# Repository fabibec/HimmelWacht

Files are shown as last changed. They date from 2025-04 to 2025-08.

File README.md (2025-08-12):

# HimmelWacht

This repository contains all the files, documentation, and source code for the HimmelWacht project. The project integrates a Raspberry Pi for high-level processing, an ESP32 for real-time hardware control, and a laboratory computer for AI model inference.

## Project Description

This project develops a Bluetooth-controller-operated vehicle equipped with a manual and semi-automatic Nerf dart launcher. The launcher fires at a wooden glider attached to a stick and moved by a person. In manual mode, the vehicle, turret platform, and launcher are controlled via the Bluetooth controller. The semi-automatic mode uses artificial intelligence and computer vision to detect the wooden glider and automatically aim the launcher, ignoring other objects. Movement is possible along both X and Y axes, with vertical motion limited to maintain the camera’s field of view. The system assumes optimal indoor conditions for target detection and tracking.

For more details refer to the [final presentation](documents/praesi/gruppe_1_himmelwacht_praesentation.pdf)

## Repository Structure

This repository is organized into the following directories:

```
.
├── cad/                 # CAD files (FreeCAD, STL) for 3D-printed components.
├── documents/           # Project documentation, datasheets, and diagrams.
├── esp/                 # ESP32 firmware and related tools.
├── laboratory_computer/ # AI models, training scripts, and inference code.
├── raspberry/           # Software for the Raspberry Pi.
└── util/                # Miscellaneous utilities, screenshots, and test files.
```

Each directory contains a `README.md` file with more detailed information about its contents and setup instructions.

## Getting Started

To get started with a specific part of the project, please refer to the `README.md` file within the corresponding directory:

- **For the ESP32 firmware**: See `esp/HimmelWachtEsp32/README.md`
- **For the Raspberry Pi code**: See `raspberry/README.md`

General project documentation can be found in the `documents/` directory.

## Authors

- Fabian Becker
- Jendrik Jürgens
- Nicolas Koch
- Michael Specht
- Jonathan Wohlrab

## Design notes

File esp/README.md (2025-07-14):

# ESP32 Code

This directory contains all code and tools related to the ESP32 microcontroller.

## Directory Structure

```
.
├── bluepad32-v4.2.0/      # Bluepad32 library for gamepad support.
├── ds4-mac-change/        # Utility to set the MAC-address of the controller.
├── esp-idf-v5.4.1/        # ESP-IDF framework.
└── HimmelWachtEsp32/      # Main ESP32 project code.
```

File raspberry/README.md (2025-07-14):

# Raspberry Pi Code

his directory contains all code that needs to be executed on the Raspberry Pi.

## Directory Structure

```
.
├── html_server/         # Python-based web server
├── mediamtx/            # Configuration for the MediaMTX media server.
├── sensors/             # Source code for the Gyroscope and Ultrasonic sensors.
├── systemd_services/    # systemd service files.
└── webRTC_sender/       # Deprecated peer-to-peer WebRTC sender script.
```

## System Setup and Configuration

### 1. Raspberry Pi Credentials

- **Username**: `hw`
- **Password**: `dt`

Access the Raspberry Pi via SSH:
```bash
ssh hw@<IP_ADDRESS>
```

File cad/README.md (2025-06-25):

# CAD-Files

This folder contains all of our CAD Files, both the ones we designed ourself and the imported ones.

## Used models
These are the models we used and adapted for our purpose

- [Turret](https://www.thingiverse.com/thing:4870102/files)
- [Raspberry PI Case](https://www.printables.com/model/705427-retro-raspberry-pi-5-case-snap-fit)
- [Flywheel Driver Holder](https://www.printables.com/model/355368-holder-for-xy-mos-d4184-power-mosfet-breakout-modu)
- [PS4 Controller Phone Holder](https://www.printables.com/model/813863-smartphone-mount-for-ps4-controller-dualshock-4/files)

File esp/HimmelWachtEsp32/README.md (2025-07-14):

# HimmelWacht ESP32 Software

This repository contains the firmware for the ESP32 microcontroller used in the HimmelWacht project. It handles low-level hardware control, including motor operation and gamepad connectivity. The project is preconfigured for use with Visual Studio Code and the C/C++ extension.

## Getting Started

Follow these steps to set up the project, build the firmware, and flash it to the ESP32.

### Prerequisites

- **ESP-IDF v5.4.1**: This project depends on a specific version of the ESP-IDF, which is included as a Git submodule in the `esp/esp-idf-v5.4.1` directory.
- **Bluepad32 v4.2.0**: The Bluepad32 library is also included as a submodule in the `esp/bluepad32-v4.2.0` directory.

### Installation and Setup

1.  **Initialize Submodules**: If you have cloned the repository without the submodules, initialize them first:
    ```shell
    git submodule update --init --recursive
    ```

2.  **Set up ESP-IDF**: Configure the build environment by running the install and export scripts.
    ```shell
    # From the project root directory
    cd esp/esp-idf-v5.4.1
    ./install.sh
    . ./export.sh
    ```
    *Note: You may need to run the `export.sh` script in every new terminal session.*

3.  **Patch Bluepad32 and BTstack**: Apply the necessary patches to the BTstack library within Bluepad32.
    ```shell
    # From the project root directory
    cd esp/bluepad32-v4.2.0/external/btstack
    git apply ../patches/*.patch
    ```

4.  **Integrate BTstack**: Run the integration script to make the patched BTstack component available to the ESP-IDF.
    ```shell
    # From the project root directory
    cd esp/bluepad32-v4.2.0/external/btstack/port/esp32
    ./integrate_btstack.py
    ```

### Building and Flashing

After completing the setup, return to the main project directory and use the `idf.py` tool to build and flash the firmware.

1.  **Navigate to the project directory**:
    ```shell
    # From the project root directory
    cd esp/HimmelWachtEsp32
    ```

2.  **Build the project**:
    ```shell
    idf.py build
    ```

3.  **Flash the firmware**: Connect the ESP32 to your computer and flash the built firmware.
    ```shell
    idf.py flash
    ```

## Technical Details

### Motor Driver

The Pololu G2 High-Power Motor Driver 24v13 board is used to control the motors. It supports two primary control modes. The current implementation uses Sign-Magnitude mode.

#### Control Modes

1.  **Sign-Magnitude (S-M)**: The PWM duty cycle controls motor speed, and a separate digital pin (`DIR`) controls the direction.
2.  **Locked-Antiphase (L-A)**: The `PWM` pin is held high, and the PWM signal is sent to the `DIR` pin to control both speed and direction.

#### Locked-Antiphase Operation

| Duty Cycle (%) | Locked-Antiphase |
| :--- | :--- |
| 0 | Full speed reverse |
| 25 | Medium speed reverse |
| 50 | Coast (motor off) |
| 75 | Medium speed forward |
| 100 | Full speed forward |

| PWM | DIR | OUTA | OUTB | Operation |
| :-- | :-- | :--- | :--- | :--- |
| H | H | H | L | Forward |
| H | L | L | H | Reverse |
| L | X | L | L | Brake |

#### Mode Comparison

| Feature | Sign-Magnitude | Locked-Antiphase |
| :--- | :--- | :--- |
| **Ease of implementation** | ✅ Very easy | ❗ A bit more complex |
| **PWM Pin Use** | PWM → speed, DIR → direction | DIR → PWM waveform, PWM = always HIGH |
| **Idle behavior (0% duty)** | Outputs both LOW = brake | DIR at 50% duty = coast |
| **PWM frequency required** | Lower okay (~20 kHz) | ⚠️ Needs higher freq (~50–100+ kHz) |
| **EMI (Electromagnetic Interference)** | Lower | Can be noisier due to polarity switching |
| **Smoothness at low speeds** | Good | ✅ Often smoother, more linear torque |
| **Power efficiency** | Slightly better | Can generate more switching losses |
| **Torque ripple** | Can be higher | ✅ Lower, smoother torque transitions |

## Dependencies

- C11
- ESP-IDF v5.4.1
- Bluepad32 v4.2.0

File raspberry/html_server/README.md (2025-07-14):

# HTML Server

This Python script starts an HTTP server that:

- Serves a static webpage which pulls a **WebRTC stream** from a MediaMTX server running on a Raspberry Pi.
- Connects to a **WebSocket** to receive bounding-box coordinates sent from the inference script running on the laboratory PC.
- Supports **real-time video annotation** in the browser using the received data.

The script creates an additional **WebSocket** which streams the real-time date of the Gyroscope and Ultrasonic sensor.

## Configuration

All network parameters (e.g., IP address of the Lab PC, port numbers) can be configured via a `.env` file.

Example `.env`:

```env
LAB_PC_IP=172.16.3.105
HTTP_PORT=8000
WEBSOCKET_PORT=8765
```

## Usage

The server is started automatically by a `systemd` service.

To apply changes (e.g., updated source code or `.env` configuration), restart the service:

```bash
sudo systemctl restart webserver.service
```

Once running, you can access the web interface at:

```
http://<your-system-ip>:<HTTP_PORT>
```

The server will log its current IP address on startup.

## Credits

The favicon used is free to use.
Source: [Missiles icon by Freepik - Flaticon](https://www.flaticon.com/free-icon/missiles_3857446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)

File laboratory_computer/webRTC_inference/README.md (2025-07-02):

# webRTC Inference

Contains the used scripts for webrtc stream, Ai inference and combines it with MQTT, Websockets and the possiblity to track objects detected with the AI.
DEPRECATED => Was used over the course of the project but has been dropped due to requirements

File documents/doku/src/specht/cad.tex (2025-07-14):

\chapter{CAD-Konstruktion}

\section{Setup und Einarbeitung (Becker, Specht)}

Zu Beginn des Projekts wurde in Abstimmung mit Fabian Becker sowie im Austausch mit Andreas Wittmann (Studienkollege) entschieden, FreeCAD als CAD-Software zu verwenden. Der Grund hierfür war die einfache Kollaboration innerhalb der Projektgruppe sowie der unkomplizierte Erfahrungsaustausch mit der Arbeitsgruppe um A. Wittmann. Andere Softwarelösungen wie OnShape wurden diskutiert, aufgrund der Komplexität und der damit verbundenen Einarbeitungszeit im Hinblick auf die Projektlaufzeit jedoch verworfen. FreeCAD ist zudem eine Open-Source-Software, die neben Fedora- auch auf Debian-Systemen lauffähig ist. So konnte die Software problemlos auf den Arbeitsrechnern der Teammitglieder installiert werden.

Grundsätzlich stützt sich die Konstruktion auf vorhandene STL-Vorlagen. Mehrere Beispielprojekte aus dem Internet dienten als Grundlage für die Arbeit \cite{cad_turret_blueprint,cad_flywheel_blueprint,cad_esp_case_blueprint, cad_gyro_blueprint, cad_servo_v1_blueprint, cad_geometry_srf02}.

\section{Geschützarm Version 1 (Specht) \label{sec:cad_gunarm_v1}}

Bevor mit der Konstruktion begonne wurde, wurde im Team besprochen, welche Komponenten nötig sind, um die Position des Flugobjekts eindeutig zu bestimmen. Die Wahl fiel auf folgende Komponenten, die aus vorherigen Studienprojekten übernommen werden konnten:

\begin{itemize}
    \item GY-521 MPU-6050 3-Achsen-Gyroskop und Beschleunigungssensor
    \item SRF02 Ultraschall Entfernungssensor
    \item Raspberry Pi 5 Kamera Modul
    \item 2x 28BYJ-48 Schrittmotor
\end{itemize}

Ziel des ersten Entwurfs war es, diese kompakt auf dem Arm zu integrieren. Die angedachten Schrittmotoren wichen jedoch von der Vorlage aus dem Beispielprojekt \cite{cad_turret_blueprint} ab, weshalb der Geschützarm von Grund auf neu konstruiert werden musste.

Alle Module sollten zentral über der Abschusseinrichtung platziert werden, um eine korrekte Berechnung der Flugbahn zu ermöglichen. Der Ultraschall-Sensor sollte dabei hochkant nach vorne gerichtet sein, um die Entfernung zum Ziel zu messen. Die Kamera sollte schräg nach oben gerichtet sein, um den Himmel zu überwachen. Der Beschleunigungssensor sollte liegend auf dem Arm montiert werden, um die Beschleunigung des Arms zu messen. Die Schrittmotoren mussten in einem geeigneten Abstand zueinander montiert werden, sodass die Flywheel-Konstruktion des Arms funktioniert. Letzteres konnte durch das Vermessen der Vorlage aus dem Beispielprojekt \cite{cad_turret_blueprint} realisiert werden. Für die restlichen Anforderungen waren die korrekten Maße nötig. Für die Montage der Kamera konnte eine bereits 3D-gedruckte Halterung aus einer anderen Gruppe benutzt werden. Die Haltevorrichtung für den Beschleunigungssensor wurde aus einer STL-Vorlage \cite{cad_gyro_blueprint} übernommen und angepasst. Auch für die Schrittmotoren konnte auf ein Modell aus dem Internet \cite{cad_servo_v1_blueprint} zurückgegriffen werden, weshalb es nicht nötig war, die komplexe Geometrie eigenständig zu vermessen. Einzig die Maße für den Ultraschall-Sensor wurden recherchiert \cite{cad_geometry_srf02} und durch Nachmessen validiert.

\begin{figure}[h]
    \centering

    \begin{subfigure}[b]{0.45\textwidth}
        \centering
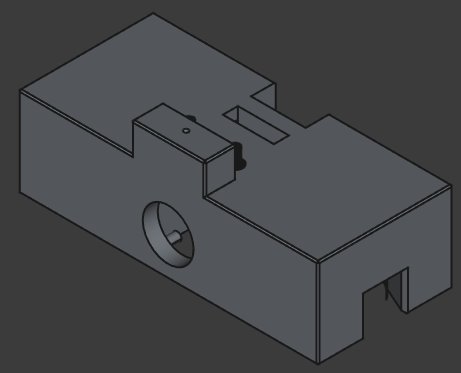
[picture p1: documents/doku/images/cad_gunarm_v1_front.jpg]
        
        \caption{Geschützarm Version 1 - Frontansicht}
    \end{subfigure}
    \hfill
    \begin{subfigure}[b]{0.45\textwidth}
        \centering
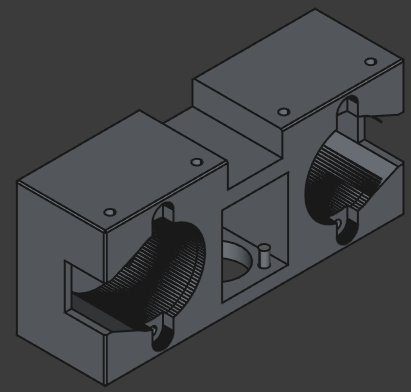
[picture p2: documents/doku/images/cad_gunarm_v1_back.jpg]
        
        \caption{Geschützarm Version 1 - Rückansicht}
    \end{subfigure}

    \caption{Geschützarm Version 1}
    \label{fig:gunarm_v1}
\end{figure}

Neben den eigentlichen Maßen der Komponenten war das Kabelmanagement ein wichtiges Thema. Alle Kabel sollten nach hinten am Magazin entlang geführt werden, um eine saubere Optik zu gewährleisten. Für Beschleunigungssensor und Kamera stellte dies kein Problem dar, da diese ganz oben angebracht sein sollten. Der Ultraschall-Sensor und die Schrittmotoren hingegen waren in das neukonstruierte Gehäuse integriert, sodass Aussparungen, wie in Abbildung~\ref{fig:gunarm_v1} zu sehen, angebracht werden mussten, um die Kabel aus dem Gehäuse herauszuführen.

Außerdem musste sichergestellt werden, dass der Geschützarm an das Magazin montiert werden kann. Hierzu wurden vom Kollegen Fabian Becker Montagepunkte am Magazin konstruiert, die mit dem Geschützarm verschraubt werden können.

\section{Geschützarm Version 2 (Specht)}

Im Laufe des Projektes wurde in Abstimmung mit Fabian Becker klar, dass die initial angedachten Schrittmotoren aufgrund zu geringer Leistung nicht für die Flywheel-Konstruktion geeignet sind. Daraufhin wurde sich für die originalen Motoren aus dem Beispielprojekt \cite{cad_turret_blueprint} entschieden. Das hatte zur Folge, dass der Geschützarm neu konstruiert werden musste, da die Maße der neuen Motoren von den Alten abwichen. Aus diesem Grund wurde der Geschützarm der Vorlage \cite{cad_turret_blueprint} als Basis genommen und die Grundidee der Version 1 beibehalten.

\begin{figure}[h]
    \centering

    \begin{subfigure}[b]{0.45\textwidth}
        \centering
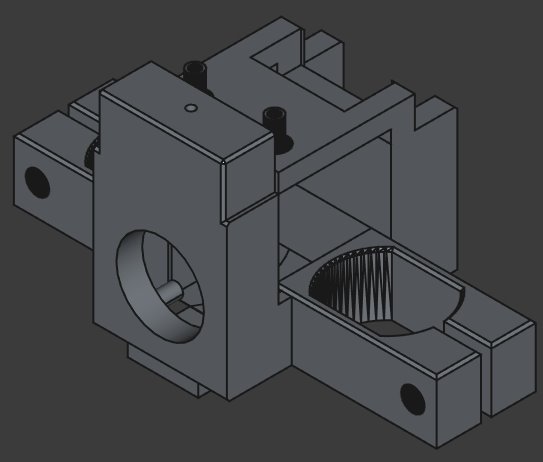
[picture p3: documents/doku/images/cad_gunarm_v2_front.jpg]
        
        \caption{Geschützarm Version 2 - Frontansicht}
    \end{subfigure}
    \hfill
    \begin{subfigure}[b]{0.45\textwidth}
        \centering
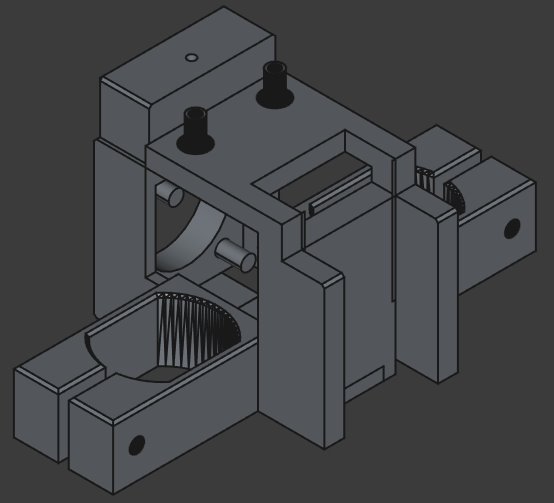
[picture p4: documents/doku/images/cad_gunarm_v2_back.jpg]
        
        \caption{Geschützarm Version 2 - Rückansicht}
    \end{subfigure}

    \caption{Geschützarm Version 2}
    \label{fig:gunarm_v2}
\end{figure}

Im Gegensatz zur Version 1 wird der Ultraschallsensor nun seitlich eingeführt anstatt von unten, siehe~\ref{fig:gunarm_v2}. Problematisch waren dabei die beschränkten Platzverhältnisse, da die Schrittmotoren näher am Kanonenrohr angebracht wurden als im vorherigen Entwurf. Außerdem wurden die zuvor angedachten Montagepunkte am Magazin wieder entfernt. Die Zusammenführung des Geschützarms mit dem Magazin erfolgte deshalb mittels Modellbaukleber.

\section{Montagehalterung Motortreiber (Specht)}

Für die ersten Funktionstests wurden die Pololu-Motoren provisorisch auf Kork-Schnipseln montiert. Dieses Vorgehen ermöglichte eine zügige Inbetriebnahme, jedoch erwies es sich hinsichtlich Stabilität und Sicherheit als unzureichend. Im Rahmen der Tests kam es zum Abrutschen eines Motors von der Korkunterlage, was zu einer kurzfristigen Wärmeentwicklung und Geruchsbildung führte. Glücklicherweise wurde eine Beschädigung der Hardware vermieden.

\begin{figure}[h]
    \centering

    \begin{subfigure}[b]{0.25\textwidth}
        \centering
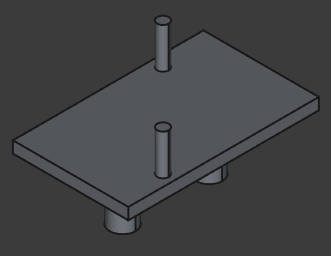
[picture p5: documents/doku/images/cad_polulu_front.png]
        
        \caption{Polulu - Draufsicht}
    \end{subfigure}
    \hspace{0.05\textwidth}
    \begin{subfigure}[b]{0.25\textwidth}
        \centering
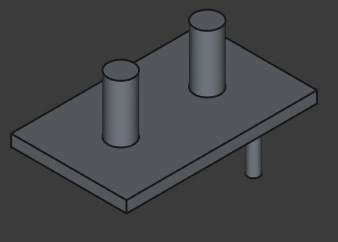
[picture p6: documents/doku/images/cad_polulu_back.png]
        
        \caption{Polulu - Bodensicht}
    \end{subfigure}

    \caption{Montagehalterung für Pololu-Motortreiber}
    \label{fig:pololu_mounting}
\end{figure}

Für die finale Abnahme wurde daher ein dauerhaftes und sicheres Montagesystem umgesetzt, das ein sauberes und zuverlässiges Setup gewährleistet. Die Maße bzw. Position der Löcher wurden dabei manuell mit Geodreieck vermessen. Wie in Abbildung~\ref{fig:pololu_mounting} zu sehen, kann die Halterung direkt auf der Montageplatte des Fahrzeugs geklippt werden.

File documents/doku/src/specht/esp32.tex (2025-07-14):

\section{Motor-Treiber (Specht)}

Wesentlich für den Einstieg in die Motor-Treiber-Programmierung waren die verwendeten Hardware-Komponenten. Folgende Teile wurden verwendet:

\begin{itemize}
    \item 2x Pololu G2 High-Power Motor Driver 24v13 (MD31C)
    \item 2x MFA/Como Drills 919D501
\end{itemize}

Im ersten Ansatz wurde der Versuch unternommen, den Low-Level-Treiber (LL-Treiber) direkt mit der Differenzialantriebs-Logik (Differentialantrieb) zu koppeln. Nach intensiver Recherche und ersten Programmieransätzen wurde jedoch deutlich, dass eine klare Trennung beider Ebenen unter modularen Gesichtspunkten vorzuziehen ist. Diese Trennung resultiert in einer signifikanten Steigerung sowohl der Wiederverwendbarkeit als auch der Wartbarkeit des Codes. Abhilfe schafften hierbei vor allem die Verwendung von ESP-IDF-Komponenten.\newline

Um die Ansteuerung der Motoren zu realisieren, war es von zentraler Bedeutung, die Spezifikationen der verwendeten Hardware zu berücksichtigen. Das Datenblatt der Pololu-Motor-Treiber wurde in Form einer Webseite gefunden \cite{pololu_g2_motor_driver}. Die darin enthaltenen Informationen waren ausreichend, um die Logik zu implementieren. \newline

Für die verwendeten Motoren lieferte das Datenblatt insbesondere elektrische Kenngrößen, die für die Absicherung der Hardware von entscheidender Bedeutung waren. Dazu zählten maximale und nominale Ströme. Zu Beginn des Projektes konnte nur auf einen 6V-Akku zurückgegriffen werden, obwohl die Motoren bis zu 12V-Betriebsspannung zulassen. Daraufhin wurden entsprechende Widerstände auf den Treiberboards angebracht, um den maximalen Strom für 6V zu begrenzen. Des Weiteren konnte aus dem Datenblatt des Pololu-Motor-Treibers die Notwendigkeit überdimensionierter Kondensatoren abgeleitet werden, um eine gute und stabile Performance sicherzustellen. \cite{mfa_como_drills_919d_series} \newline

Der Fokus der Implementierung lag vorrangig auf Modularität, Erweiterbarkeit, Clean-Code und Best-Practices. Deshalb wurde wenn möglich auf globale Variablen verzichtet und stattdessen auf die Verwendung von Strukturen und Funktionen in Kombination mit Pointern gesetzt.

\subsection{Low-Level Treiber}

Die Aufgabe des LL-Treibers bestand darin, genau einen Motor anzusprechen und zu steuern. Das verwendete Framework ESP-IDF bietet eine Vielzahl an API-Funktionen, die eine abstrahierte und einfache Ansteuerung der Hardware ermöglichen. Für das Erzeugen von PWM-Signalen sind vor allem zwei API's von zentraler Bedeutung:

\begin{itemize}
    \item LED Control (LEDC)
    \item Motor Control Pulse Width Modulator (MCPWM)
\end{itemize}

Wie den Namen zu entnehmen ist, ist LEDC für die einfache Ansteuerung von LEDs gedacht \cite{esp32_ledc}, während MCPWM speziell für Motoren entwickelt wurde \cite{esp32_mcpwm}. Der MCPWM-Generator besteht aus einer Reihe von Submodulen, wie bspw. einem Fault-Module und einem Brake-Operator. Die Pololu-Boards bieten ebenfalls einen Fault-Pin, weshalb im weiteren Projektverlauf der MCPWM-Generator verwendet wurde, um diese Funktionalität nutzen zu können. \newline

Die MCPWM-API umfasst mehrere Funktionen und Strukturen. Deswegen wurde der erste Entwurf auf Basis einer Kombination aus KI-generiertem Code und Beispielcode von Github erstellt \cite{esp32_mcpwm_example}. Die grundlegende Funktionalität konnte dadurch unkompliziert und schnell erfasst werden, wodurch Zeit gespart wurde. Nichtsdestotrotz war es notwendig, entsprechende Literatur zur API zu lesen und zu verstehen. Im Folgenden wurde der Code schrittweise angepasst, modularisiert und erweitert. \newline

Ein Key-Konzept entstand aus dem Gedanken, was passieren würde, wenn ein Duty-Cycle von beispielsweise 100 \% (Volllast) gesetzt wird und die Drehrichtung des Motors umgekehrt wird. Die Annahme war, dass der Motortreiber + und - umpolt und der Motor solange als Generator arbeitet, bis die Richtung letztendlich umgekehrt wird. Der dabei möglicherweise auftretende Rückstrom könnte eventuell die Hardware beschädigen. Aus diesem Grund wurde sich auf eine Ramping-Strategie festgelegt, die eine sichere und kontrollierte Änderung der Drehrichtung ermöglicht. Dabei soll sichergestellt werden, dass es nicht möglich ist, die Richtung für den Motor abrupt zu ändern. Stattdessen wird der Duty-Cycle in konfigurierbaren Schritten dem Nullbereich angenähert. In einem sicheren Hysteresebereich wird dann die Richtung geändert und der Duty-Cycle der neuen gewünschten Geschwindigkeit angepasst. \newline

Ein weiterer wichtiger Baustein sollte das automatisierte Erkennen von Fehlern der Motoren sein. In solch einem Fall sollte der Motor sofort gestoppt werden und eine Signalleuchte angehen. Ein einfacher Testaufbau bestehend aus Pull-up Widerständen und einer LED sollte die grundlegende Funktionalität des Fault-Pins sicherstellen. Der Fault-Pin ist laut Datenblatt ein Open-Drain-Ausgang, der bei einem Fehler auf Low gezogen wird \cite{pololu_g2_motor_driver}. Im Testaufbau wurde ein Pull-Up-Widerstand von 10 k$\Omega$ verwendet, um den Pin im Normalfall auf High zu halten. Folgendes Verhalten wurde erwartet: Bei einem Fehler wird der Pin auf Low gezogen und die LED leuchtet auf. Dies war jedoch nicht der Fall. Stattdessen leuchtete die LED dauerhaft, obwohl der Motor einwandfrei funktionierte. Nach Rücksprache mit dem Betreuer stellte sich heraus, dass dieser Pin in der Vergangenheit nie benutzt wurde. Um den Projektfortschritt nicht unnötig zu gefährden, wurde beschlossen, den Fault-Pin nicht weiter zu verwenden und mit der Implementierung des Differentialantrieb fortzufahren.

\subsection{Testing}

Das Testing unterteilte sich in mehrere Schritte. Für die Erstellung der Testfälle wurde dabei zum Großteil KI-generierter Code verwendet. Dadurch konnte der damit verbundene Zeitaufwand signifikant minimiert und zugleich eine ausreichende Testabdeckung garantiert werden. \newline

Zunächst sollte die grundlegende Funktionalität des LL-Treibers getestet werden. Dazu wurden LEDs auf einem Breadboard angebracht, welche die Motoren simulieren sollten. Die Helligkeit der LEDs sollte dabei die Geschwindigkeit des Motors repräsentieren. \newline

Nach erfolgreicher Validierung der Ergebnisse wurde der Testaufbau an die echte Hardware angepasst. Zudem sollte ein Wrapper erstellt werden, der beide Motoren über einzelne Treiber-Objekte anspricht. Dies stellte somit eine Vorstufe zum Differentialantrieb dar. Ziel war es, die beiden Motoren unabhängig voneinander ansteuern zu können. Dafür wurde das Fahrzeug auf einer Holzkonstruktion bestehend aus zwei Holzlatten platziert. Obwohl die Tests positiv verliefen, sollte sich der Test ohne Bodenkontakt im weiteren Projektverlauf als suboptimal herausstellen.

\subsection{Differentialantrieb}

Die Grundidee des Differentialantriebs ist aus der Robotik abgeleitet und beschreibt eine Antriebsart, bei der die Bewegung eines Fahrzeugs durch die unterschiedliche Drehgeschwindigkeit der Räder auf beiden Seiten gesteuert wird \cite{design_and_control_for_differential_drive_mobile_robot}. In diesem Fall sind an jeder Seite des Fahrzeugs zwei Räder angebracht. Die beiden Räder jeder Seite werden von einem Motor angetrieben, der über einen Keilrippenriemen mit den Rädern verbunden ist. Dies hat den Vorteil, dass die Balance des Fahrzeugs verbessert wird und eine höhere Stabilität erreicht wird. Die Konstruktion konnte aus einem Projekt des Vorsemesters übernommen werden. \newline

Um ein reibungsloses Fahrerlebnis zu gewährleisten, ist es notwendig, die Geschwindigkeit und Richtung der Motoren individuell steuern zu können. Dies wird durch die Verwendung des zuvor beschriebenen LL-Treibers erreicht. Pro Motor wird ein Handle des LL-Treibers erstellt. \newline

Der Fahralgorithmus wurde so konzipiert, dass er die Controllerwerte des PS4-Controllers in Geschwindigkeiten und Richtungen umwandelt. Der Wertebereich für die horizontale Achse (Lenkung) reicht von -512 bis +512, wobei -512 die maximale linke Lenkung und +512 die maximale rechte Lenkung darstellt. Der Wertebereich für die vertikale Achse (Fahren) reicht von +512 bis -512. Da diese Skalierung unintuitiv ist, wurde das Vorzeichen gedreht. Somit steht -512 für die maximale Rückwärtsfahrt und +512 für die maximale Vorwärtsfahrt. Ein Wert von 0 bedeutet, dass der Stick in der Mitte ist und somit keine Bewegung stattfindet. Dieses Szenario ist aufgrund des Stick-Drifts des linken Sticks jedoch nicht gegeben. Eine zusätzliche Prüfung im Code auf eine sog. Deadzone ist mit überschaubarem Aufwand zu erzielen, wurde aufgrund eines Workaround, der zudem auch die Anzahl der Befehle in der Queue reduziert, jedoch nicht implementiert. Weitere Informationen dazu sind im Abschnitt \ref{sec:diff_drive_integration} zu finden. \newline

Die Logik des Fahralgorithmus stützt sich dabei auf folgende Spezifikationen:

\begin{itemize}
    \item Synchrones Fahren: Beide Motoren mit gleicher Geschwindigkeit.
    \item Lenkung Fahren: Unterscheidung zwischen sanfter und harter Lenkung.
    \begin{itemize}
        \item Sanft: Inneren Motor stoppen.
        \item Hart: Inneren Motor entgegengesetzt.
    \end{itemize}
    \item Stop: Beide Motoren stoppen.
    \item Drehung Stand: Je nach Richtung Motoren entgegengesetzt.
\end{itemize}

Für das synchrone Fahren und die Drehung im Stand ist es wichtig, dass kleinere Änderungen wie beispielswiese Stick-Drift oder eine nicht perfekte Haltung des Sticks nicht unnötig zu einer abrupten Änderung führen. Deshalb wurde für das synchrone Fahren ein Hysteresebereich in X-Richtung von $|75|$ festgelegt. Befindet sich die horizontale Achse innerhalb dieses Bereichs, so bestimmt die vertikale Achse die Geschwindigkeit. Selbiges gilt für die Drehung im Stand, wobei hier der Hysteresebereich in Y-Richtung von $|75|$ festgelegt wurde und die horizontale Achse die Drehrichtung bestimmt. Um dies in Kombination mit der Nullposition und den anderen Parametern zu verdeutlichen, wurde eine Abbildung erstellt, die die Logik des Differentialantriebs veranschaulicht. \newline

\begin{figure}[H]
    \centering
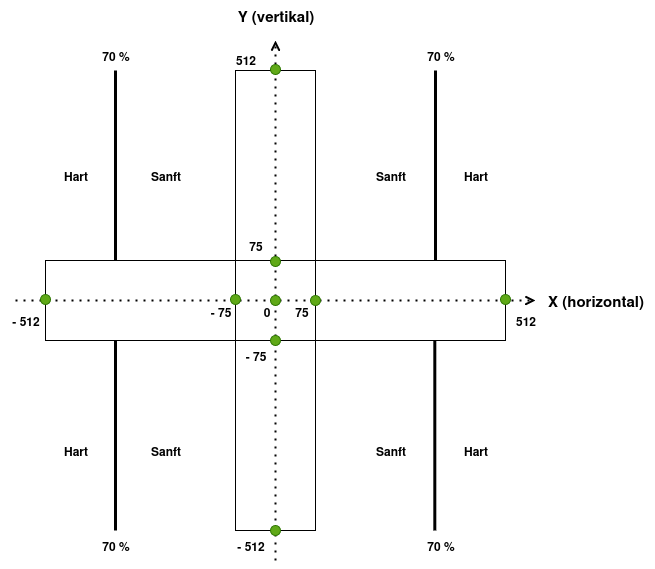
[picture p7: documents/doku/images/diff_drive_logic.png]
    
    \caption{Differentialantrieb Logik}
    \label{fig:diff_drive_logic}
\end{figure}

Im Zentrum der Abbildung~\ref{fig:diff_drive_logic} befindet sich die Nullposition. Der Grund dafür wird im Abschnitt \ref{sec:diff_drive_integration} erläutert. Die beiden Kanäle im Bereich $|75|$ in X- bzw. Y-Richtung sind die Hysteresebereiche für die Geschwindigkeit bzw. die Drehung im Stand. Die äußeren Bereiche sind für das Fahren mit Lenkung relevant. Die 70 \% Markierungen symbolisieren dabei die Abgrenzung zwischen sanfter und harter Lenkung.

Nachdem die Logik des Differentialantriebs implementiert war, konnte der Task und die damit verbundenen notwendigen Funktionen erstellt werden. Als Schnittstelle fungiert die Funktion \textit{diff\_drive\_send\_cmd}. Diese verarbeitet die Werte des Controllers in dem sie auf den zuvor beschriebenen Algorithmus zurückgreift. Anschließend sendet sie die berechneten Werte an die Queue des Tasks. Der Task selbst greift periodisch auf die Queue zu und appliziert die Befehle an die Steuerungslogik. Die Frequenz des Tasks wurde für Testingzwecke variabel gehalten, um diese auch später noch adaptieren zu können. Ein wichtiger Bestandteil der Tasklogik besteht darin, dass die Motoren nicht nur beim Erhalt neuer Werte angesteuert werden, sondern auch in regelmäßigen Abständen Updates erhalten. Dies ist essenziell, um die eingangs beschriebene Ramping-Strategie konsequent umzusetzen. \newline

Mit dem Kollegen Fabian Becker wurde sich zudem abschließend geeinigt, dass mathematische Berechnungen auf dem ESP32, sofern möglich, mittels Festkommaarithmetik durchgeführt werden sollen. Die IQMath-Bibliothek wurde dafür verwendet. Diese ermöglicht es, Gleitkommarechnungen in Festkommaoperationen umzuwandeln \cite{esp32_iqmath}. Dadurch soll die Geschwindigkeit der Berechnungen erhöht, die Speicherauslastung reduziert und die Performance des Codes verbessert werden \cite{esp32_iqmath}. Die Idee wurde aus der Robotik-Vorlesung von Prof. Dr. Metzner entnommen, in der die Vorteile von Festkommaarithmetik im Vergleich zu Gleitkommaarithmetik hervorgehoben werden. \newline

Messbare Unterschiede in der Performance konnten jedoch nicht festgestellt werden. Der Grund dafür könnte sein, dass die Logik des Differentialantriebs mehr auf einfacheren Operationen basiert, die über verschachtelte IF-Anweisungen ausgewertet werden, wodurch diese nicht von der Festkommarithmetik profitiert. Auch eine Ressourcenoptimierung in Hinblick auf den Speicher konnte nicht festgestellt werden. Die Speicherauslastung wies keine Unterschiede auf. Nichtsdestotrotz wurde der Ansatz beibehalten, da es sich um eine Best-Practice im Bereich der Mikrokontroller-Programmierung handelt und die Basis für komplexere Berechnungen bildet. \newline

\subsection{Testing} \label{sec:diff_drive_tests}

Wie beim Testing des LL-Treibers, wurde der Code auch hier größtenteils KI-generiert. In der Summe gab es zwei Testszenarien:

\begin{itemize}
    \item Logik-Test auf Holzkonstruktion
    \item Logik-Test auf Laborboden
\end{itemize}

Im ersten Fall fielen gleich zu Beginn kleinere Fehler, wie beispielsweise das fehlerhafte Freigeben von Ressourcen, auf. Diese konnten umgehend behoben werden. Trotz der Anpassungen war ein größeres Problem ersichtlich: Die rechte Antriebsseite funktionierte nicht. Der linke Antriebsstrang lief zwar mit der korrekten Geschwindigkeit, dafür passten hier die Richtungswechsel nicht. \newline

Für Debuggung-Zwecke bietet das verwendete Framework ESP-IDF einen Loggingmechanismus an, der es ermöglicht, den Status von Variablen in Form von Konsolenausgaben nachzuvollziehen. Dafür ist es notwendig, dass der ESP32 über die USB-Schnittstelle mit dem Rechner verbunden ist. \newline

Folgendes Verhalten wurde festgestellt: Die Werte wurden korrekt berechnet, die Queue jedoch nicht richtig abgearbeitet. Das Problem lag bei der Initialisierung der Queue, welche Steuerbefehle entgegennimmt. Die API erlaubt es, Pointer auf Structs oder eine Kopie des Structs als Queuewerte festzulegen. Im Code wurde beim Laden der Werte aus der Queue das komplette Struct angegeben, beim Laden in die Queue hingegen nur ein Pointer. Aufgrund der Pointergröße konnten nur die ersten 8-Byte richtige Werte enthalten, der Rest enthielt Zufallswerte. Durch Padding/Aligning des Compilers wurde die erste Variable (Speed links, float, 4 Byte) offensichtlich auf 8 Byte skaliert. Dadurch kam es zu dem undefinierten Verhalten, dass nur die linke Seite eine Drehzahl hatte. Die Richtung wurde aus einem Standardwert übernommen. Bei der rechten Seite traf man die Annahme, dass ein Zufallswert aus dem Speicher genommen wurde. Mit großer Wahrscheinlichkeit war dieser außerhalb des Bereichs, weshalb 0 (keine Drehzahl) angenommen wurde. Nach Anpassung der Queue-Parameter liefen beide Motoren mit der gewünschten Geschwindigkeit und die Richtungen konnten entsprechend korrekt gewechselt. \newline

Im zweiten Fall wurde das Fahrzeug auf den Boden des Labors gestellt. Nach einem Timeout von 10 Sekunden sollte das Fahrzeug eine spezifizierte Routine durchlaufen, bei der das Drehverhalten im Stand, Beschleunigen bzw. Abbremsen und gegensätzliches Lenken getestet wurde. Die Beschleunigungstests verliefen durchwegs positiv. Tests, welche hingegen mit einer Drehung des Fahrzeugs bzw. Lenkung in Verbindung standen, wurden nicht erfolgreich abgeschlossen. Erste Versuche, die Ursache zu finden, ließen darauf schließen, dass die Motoren nicht ausreichend Leistung haben, um das Fahrzeug zu drehen. Nach eingehenden Untersuchungen im Labor - auch in Verbindung mit dem Betreuer - wurde festgestellt, dass die zuvor aufgelöteten Widerstände, die den Strom bei 6V Betriebsspannung begrenzen sollten, zu hoch dimensioniert waren. Selbst beim Anlegen einer höheren Spannung von 12V war es nicht möglich, das Fahrzeug zu drehen. Nach Entfernen der Widerstände und Anlegen von 12V Betriebsspannung konnte das Fahrzeug wie gewünscht drehen. \newline

\section{MQTT-Anbindung (Specht)}

Für den semi-automatischen Modus ist es von zentraler Bedeutung, dass das Fahrzeug Befehle für die Geschützsteuerung empfangen kann. In Abstimmung mit dem Kollegen Jürgens wurde beschlossen, die Kommunikation zwischen KI-Komponente und Fahrzeug über MQTT umzusetzen. MQTT ist ein leichtgewichtiges Publish-Subscribe-Protokoll, das auch in Industrielösungen zum Einsatz kommt. Im ISO/OSI Referenzmodell entspricht es der Anwendungsschicht. In diesem Fall übernimmt der ESP32 die Rolle des Clients, der über einen zuvor festgelegten Topic Nachrichten empfängt. Die Fahrzeugsteuerung wurde deshalb so erweitert, dass sie auf den Topic lauscht. Demnach empfängt und verarbeitet die Fahrzeugsteuerung Nachrichten, die vom Zentralrechner, auf dem die KI-Komponente und der MQTT-Broker laufen, gesendet werden. \newline

\subsection{WiFi-Stack}

Der ESP32 bietet zwei Möglichkeiten, um eine Verbindung zu einem WLAN-Netzwerk herzustellen \cite{esp32_wifi_getting_started}. \newline

Methode 1 nutzt die Hilfefunktion \textit{example\_connect}. Diese arbeitet beim Verbindungsaufbau nach dem Busy-Waiting-Prinzip, denn sie blockt so lange, bis eine Verbindung zum Netzwerk besteht und eine IP-Adresse zugewiesen wurde. Um die Verwendung der Funktion einfach zu gestalten, werden mögliche Fehlerfälle wie beispielsweise ein Timeout nicht ordentlich behandelt. Die Funktion ist somit nur begrenzt einsetzbar und für den produktiven Einsatz nicht geeignet. \cite{esp32_example_connect} \newline

Ein weiterer Nachteil dieser Variante ist, dass das Setzen der Credentials (SSID und Passwort) normalerweise über die Konsole mittels \textit{idf.py menuconfig} erfolgt \cite{esp32_wifi_getting_started}. Beim Testing fiel auf, dass dies auf dem im Projekt zum Einsatz kommenden ESP32 nicht funktioniert. \newline

Die zweite Methode nutzt die WiFi-API des ESP-IDF. Trotz erhöhter Komplexität bietet dieser Weg eine bessere Fehlerbehandlung und im Allgemeinen ein flexibleres Interface. Aufgrund dessen wurde sich für die zweite Methode entschieden. \newline

Aus dem Developer Portal von Espressif \cite{esp32_wifi_getting_started} konnte eine Beispielimplementierung entnommen werden, die die grundlegende Funktionalität des Verbindungsaufbaus demonstriert. Diese wurde als Grundlage für die Implementierung der WiFi-Komponente verwendet. Trotz diverser Möglichkeiten, den WiFi-Stack noch zu optimieren, war die Idee diesen dennoch einfach zu halten. Hauptgrund für diese Entscheidung war, dass der WiFi-Stack und der damit verbundene MQTT-Stack zusätzliche Speicherresourcen benötigen, obwohl der Speicher aufgrund der Vielzahl an implementierten Komponenten bereits begrenzt ist. \newline

\subsection{MQTT-Stack}

Bevor mit der Programmierung begonnen werden konnte war es notwendig, sich mit der API des MQTT-Stacks auseinanderzusetzen. Abhilfe schaffte hierbei die Dokumentation des ESP-IDF \cite{esp32_mqtt}. Das Framework bietet neben TCP auch eine Reihe verschlüsselter Übertragungswege, wie beispielsweise TSL. Wegen der damit verbundenen erhöhten Komplexität und Einarbeitungszeit wurde sich aber in Absprache mit dem Kollegen Jürgens auf eine MQTT-Kommunikation mittels TCP ohne Verschlüsselung geeinigt. Neben den Netzwerkeigenschaften und den API-Details enthält die Dokumentation auch Referenzen zu Beispielen in deren Github-Repository. So konnte die grundlegende Funktionalität anhand des Beispielscodes zügig erstellt werden \cite{esp32_mqtt_example}. Das Programm stellt jedoch nur eine einfache Implementierung dar, die zur Orientierung dienen soll und für den Einsatz in größeren Projekten nicht geeignet ist. Deshalb waren weitere Anpassungen notwendig. Dabei wurde auf eine Kombination aus KI-generiertem Code, Beispielcode und eigener Implementierung zurückgegriffen. Die eigene Implementierung stützt sich dabei auf die Erkenntnisse aus der Analyse der Dokumentation. Darüber hinaus wurde großer Wert auf Konformität mit den bereits implementierten Komponenten gelegt. Dies betrifft insbesondere das Abfragen der Geschütz- und Feuersteuerung, das ebenfalls über Queues realisiert wird. \newline

Für die Verarbeitung der erhaltenen Nachrichten ist das Format der Daten von zentraler Bedeutung. Die Nachrichten werden im JSON-Format gesendet. Dies bietet einen einfachen Weg, um strukturierte Daten mit einem geringen Overhead zu übertragen. Die Nachrichten weisen dabei folgende Struktur auf:

\begin{lstlisting}
{
  "platform_x_angle": -45,
  "platform_y_angle": 80,
  "fire_command": false
}
\end{lstlisting}

Beide Winkel sind in der Einheit Grad angegeben. Der X-Winkel beschreibt die horizontale Ausrichtung des Geschützes im Bereich -90 bis +90 Grad, wobei -90 Grad nach links und +90 Grad nach rechts zeigt. Die Grad-Werte für den Y-Winkel bzw. die vertikale Orientierung liegen im Bereich 0 bis 80 Grad, wobei 48 Grad der Nullposition entspricht. Die Werte sind der Platform-Control entnommen und wurden vom Kollegen Becker entsprechend getestet. \newline

Das Kommando \textit{fire\_command} ist ein boolescher Wert, der angibt, ob das Geschütz feuern soll oder nicht. Prinzipiell ist dieser Wert im semi-automatischen Modus nicht relevant und somit immer \textit{false}, da der Feuerbefehl nur manuell ausgelöst werden kann. Um zukünftig eine automatische Feuersteuerung zu ermöglichen, wurde dieser Wert dennoch in die Nachrichtenstruktur aufgenommen. \newline

Die Nachrichten werden über den Topic \textit{vehicle/turret/cmd} gesendet. Da im Projekt MQTT über TCP implementiert wrude, ist es potentiell möglich, dass von anderen Netzwerkteilnehmern Nachrichten an den Topic gesendet werden. Dies wurde jedoch nicht weiter berücksichtigt, da das Fahrzeug in einem dedizierten Netzwerk betrieben wird. \newline

\subsection{Testing}

Erste Tests der MQTT-Komponente konnten ohne Fahrzeug durchgeführt werden. Dazu wurde \textit{mosquitto} als MQTT-Broker auf dem Rechner installiert. Mit Hilfe des Tools \textit{mosquitto\_pub} können Nachrichten an den Topic gesendet werden. Mittels der bereits unter Abschnitt~\ref{sec:diff_drive_tests} beschriebenen Logging-Funktionalität des ESP-IDF konnte die korrekte Verarbeitung der Nachrichten mit Hilfe von Konsolenausgaben überprüft werden. Die Nachrichten wurden dabei korrekt empfangen.

\section{Integration/Fahrzeugsteuerung (Becker, Specht) \label{sec:esp32_integration}}

Die Fahrzeugsteuerung ist eine Abstraktionsebene, die als zentrale Anlaufstelle für Befehle vom Controller dient. Darin ist der Haupttask implementiert, der die Steuerbefehle entgegennimmt und an die entsprechenden Queues weiterleitet. Diese Queues werden dann von den Tasks der jeweiligen Komponenten abgearbeitet. Neben der Geschütz- und der Feuersteuerung ist auch die Ansteuerung der Differentialantriebs-Logik eine der zentralen Komponenten. Darüber hinaus ist die Fahrzeugsteuerung auch das Modul, das letztendlich in der Main-Methode mithilfe diverser komponenten-spezifischer Strukturen initialisiert wird. \newline

\subsection{Regelschleife (Becker)} \label{sec:esp32_control_loop}

Die Grundlage der Fahrzeugsteuerung bildet eine Regelschleife, welche synchron zur Update-Frequenz des DualShock4-Treibers mit 60 Hz ausgeführt wird. 
Zunächst wird in dieser Schleife gewartet, bis eine Verbindung zum Controller hergestellt wurde.
Im Anschluss daran wird der aktuelle Status des Controllers aus der entsprechenden Queue abgerufen (vgl. Abbildung \ref{fig:ds4_driver}).

Abhängig vom aktuellen Modus, also dem Zustand, in dem sich das Fahrzeug befindet, werden mit diesen Daten verschiedene Berechnungen durchgeführt. 
Das Fahrzeug verfügt über zwei Modi:

\begin{itemize}
    \item Im \textbf{manuellen Modus} erfolgt die Steuerung des Fahrzeugs, der Plattform sowie die Schussabgabe manuell über den DualShock4-Controller.
    \item Im \textbf{semi-automatischer Modus} wird die Steuerung der Plattform durch ein KI-Modell übernommen.
\end{itemize}

Der aktuelle Modus ist anhand der Lichtleiste des Controllers erkennbar:
Im manuellen Modus leuchtet die Lichtleiste in einem hellen Grün, während sie im semi-automatischen Modus in einem orangen Farbton leuchtet.
Der Modus kann durch gleichzeitiges Halten der oberen Pfeiltaste und der Kreuztaste für 1.5 Sekunden gewechselt werden, beim Moduswechsel vibriert der Controller für einen kurzen Moment.

\subsection{Plattformsteuerung \& Schussabgabe (Becker)} \label{sec:platform_integration}

Die Plattform wird im manuellen Modus anhand der Eingabe des Joysticks gesteuert, wobei zuerst die digitalisierten Werte des analogen Controller-Sticks in Winkel umgerechnet werden müssen.
Dafür werden folgende Schritte ausgeführt:

\begin{enumerate}
    \item \textbf{Deadzone-Filter} \newline
    Um kleine Bewegungen des Joysticks, die durch Stick-Drift entstehen, zu ignorieren, wird ein Deadzone-Filter angewendet.
    Wenn der Wert des Controller-Sticks kleiner als ein bestimmter Schwellenwert ist, wird der Wert auf null gesetzt, um ungewollte Eingaben zu vermeiden.
    \[
    \text{if} \left( |\text{stick}| < \text{deadzone} \right) \text{ then stick} = 0
    \]

    \item \textbf{Normalisierung} \newline
    Die vorliegenden Digitalwerte des Sticks werden nun vom Intervall ]-512, 512[ auf das Interval von ]-1, 1[ normalisiert.
    \[
    \text{normalized\_stick} = \frac{\text{stick}}{512}
    \]

    \item \textbf{Low-Pass-Filter zur Glättung der Eingabe} \newline
    Ein Low-Pass-Filter wird verwendet, um schnelle Schwankungen zu glätten und sanfte Bewegungen zu erzeugen. 
    Dieser wurde hinzugefügt, da es bei schneller Drehung durch heftiges Bewegen des Sticks häufig zu zitterigen Drehbewegungen kam.
    Der Filter berechnet einen geglätteten Wert basierend auf der aktuellen Eingabe sowie dem vorherigen Wert, wodurch schnelle Änderungen abgeflacht werden.
    \[
    \text{filtered\_stick} = \alpha \cdot \text{normalized\_stick} + (1 - \alpha) \cdot \text{filtered\_stick\_previous}
    \]

    Da \( \alpha = 0.2 \) beträgt, fließt die aktuelle Eingabe lediglich zu 20 Prozent in die Berechnung ein, während der vorherige Wert zu 80 Prozent berücksichtigt wird. 
    Dieser Wert wurde manuell gewählt, da hier zitterige Drehungen am besten verhindert werden.

    \item \textbf{Berechnung der Geschwindigkeit} \newline
    Die Geschwindigkeit der Plattform wird durch die gefilterte Eingabe sowie den maximalen Drehwinkel pro Sekunde berechnet. 
    So wird sichergestellt, dass die Plattform lediglich mit einer Geschwindigkeit rotiert, die von den Servos verarbeitet werden kann. 
    Der Wert wurde anhand des Datenblatts \cite{esp_platform_servo} festgelegt und anschließend an beiden Plattformachsen reduziert, um eine übermäßige Empfindlichkeit gegenüber Controller-Eingaben zu vermeiden.
    \[
    \text{speed} = \text{filtered\_stick} \cdot \text{max\_deg\_per\_sec}
    \]

    \item \textbf{Berechnung des neuen Winkels} \newline
    Schließlich wird der Winkel der Plattform auf Basis der berechneten Geschwindigkeit und der Zeitdifferenz ($dt$, der Abstand zwischen den Regelzyklen) angepasst. 
    \[
    \text{platform\_angle} = \text{platform\_angle} \pm (\text{speed} \cdot \text{dt})
    \]
    Ob Addition oder Subtraktionverwendet wird, basiert hierbei auf der Verbaurichtung des Servomotors.
\end{enumerate}

Durch diese Berechnungen lässt sich die Plattform nun über die vertikale Achse des rechten Sticks des DualShock4-Controllers drehen und über die horizontale Achse neigen. 
Bedauerlicherweise führen die Vibrationen des Geschützaufbaus, insbesondere bei längerer und schnellerer Drehung, weiterhin zu ruckartigen Bewegungen der Motoren. 
Es konnte beobachtet werden, dass sich das Verhalten durch den Einsatz eines Low-Pass-Filters marginal verbessert hat. Aufgrund von Zeitmangel konnten keine weiteren Lösungsansätze mehr in Betracht gezogen werden. 
Ein möglicher Ansatz wäre beispielsweise der Wechsel der Servomotoren zu digitalen Motoren, die ein genaueres Feedback liefern, oder der Einbau einer PID-Regelung.

Zusätzlich wird, sobald der Nutzer die Enden der Drehwinkel erreicht hat, haptisches Feedback in Form von Vibration des Controllers an den Nutzer weitergegeben. 
Durch das Halten der Kreistaste ist es im manuellen Modus ebenfalls möglich, sich zurück auf die Nullposition beider Achsen zu bewegen.

Die Schussabgabe erfolgt über den rechten unteren Trigger des Controllers, analog zur Steuerung in bekannten Shootern. 
Da der Treiber die Position des Triggers als 10-Bit-Wert liefert, wurde ein Threshold-Wert von 800 gewählt, um wirklich nur gewollten Druck zu registrieren und nicht versehentlich Schüsse abzufeuern.

\subsection{Differentialantrieb (Specht)} \label{sec:diff_drive_integration}

Die Integration in die bestehende Code-Basis war relativ unkompliziert, da das Abgreifen der Steuerbefehle über den PS4-Treiber einfach handzuhaben ist. Ein Struct enthält alle notwendigen Stick- bzw. Button-Werte, die potenziell am Controller gedrückt werden können. Problematisch war jedoch der Stick-Drift des linken Sticks, denn dadurch wurde mit jedem Abgreifen der Werte eine Änderung im Task detektiert. Die ersten Befehle konnten teilweise noch übermittelt werden, jedoch lief nach kurzer Zeit die Queue über und es kam zu einem Absturz des Programms. \newline

Die Lösung des Problems bestand darin, den Stick-Drift einzudämmen. Daraufhin wurde durch Ausprobieren am Fahrzeug ein Grenzwert ermittelt, ab dem ein neuer Befehl interpretiert werden sollte. Dieser Wert wurde in der Fahrzeugsteuerung als Deadzone definiert. Wenn der linke Stick des Controllers innerhalb dieser Deadzone bewegt wird, wird die Geschwindigkeit des Fahrzeugs nicht angepasst. Dadurch wird verhindert, dass die Queue überläuft und das Programm abstürzt. \newline

Allerdings wurde infolgedessen festgestellt, dass die Queue im Stand überläuft, wenn der linke Stick nicht bewegt wird. Das Problem war, dass die bis dato verwendete Grenzwerte für das Detektieren neuer Steuerbefehle anfangs geringer waren als der Stick-Drift im Stand. Dadurch versuchte das Fahrzeug im Stand permanent die Geschwindigkeit anzupassen was ebenfalls zu einem Überlaufen der Queue führte. Dies war meistens visuell nicht sichtbar, sondern äußerte sich nur akustisch durch ein minimales Pfeifen der Motoren. \newline

Deshalb wurde, wie im Zentrum der Abbildung~\ref{fig:diff_drive_logic} zu sehen, eine Nullposition definiert. Diese wird beim Auftreten, sprich Nicht-Bewegen des linken Sticks, detektiert. Daraufhin wird ein Stop eingeleitet. Sobald dieser abgearbeitet wurde wird ein Flag gesetzt, das anzeigt, dass die Nullposition bereits abgearbeitet wurde. Somit wird verhindert, dass das Stoppen unnötig wiederholt wird und die Queue überläuft. Sobald der linke Stick wieder über die Grenzen der Deadzone bewegt wird, wird das Flag zurückgesetzt und die Geschwindigkeit des Fahrzeugs angepasst. \newline

\subsection{MQTT-Anbindung (Specht)}

Um die MQTT-Komponente in der Fahrzeugsteuerung nutzen zu können, waren Code-seitig nur wenige Anpassungen notwendig. Die Regelschleife, vgl. Abschnitt~\ref{sec:esp32_control_loop}, wurde so erweitert, dass eine Unterscheidung des Modus, wie bereits durch den Kollegen Becker beschrieben, vorgenommen wird. Zu Beginn des Projekts wurde der manuelle Modus priorisiert, weshalb in diesem Integrationsschritt Änderungen vorgenommen mussten, um auch den semi-automatischen Modus vollumfänglich nutzen zu können. \newline

Beim Kompilieren des Codes kam daraufhin eine Meldung, dass die Größe des erzeugten Binarys (1,254,496 bytes) den verfügbaren Speicher (1,048,576 bytes - 1MB) überschreitet. Der erste Eindruck war, dass dies vorrangig auf die Vielzahl an Komponenten zurückzuführen, die im Projekt implementiert wurden, zurückzuführen ist.

\begin{figure}[H]
    \centering
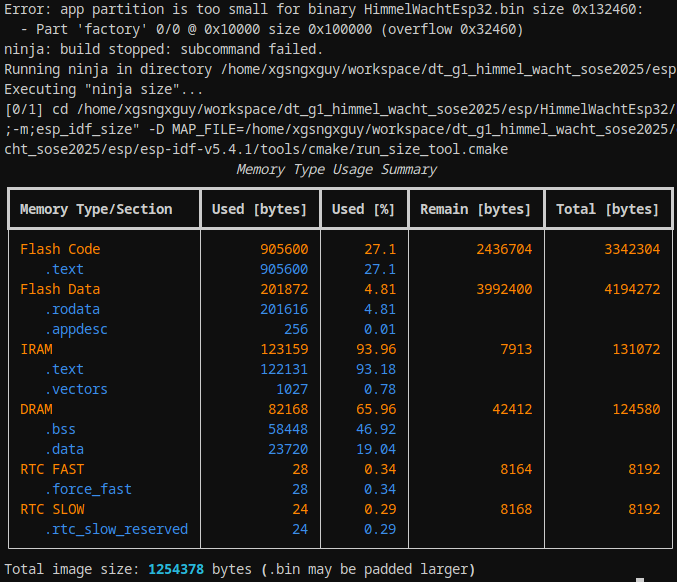
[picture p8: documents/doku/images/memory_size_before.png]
    
    \caption{Speicherauslastung vor der Optimierung}
    \label{fig:memory_size_before}
\end{figure}

Die Ausgabe der Speicherauslastung, wie in Abbildung~\ref{fig:memory_size_before} zu sehen, erfolgt über die Anweisung \textit{idf.py size}. Sie zeigt zwar zum einen den Fehler an sich, jedoch auch, dass noch etwas Speicher verfügbar ist. Nach eingehender Analyse konnte damit das Problem isoliert werden. Grund war nicht, dass prinzipiell zu wenig Speicher zur Verfügung stand, sondern dass die Konfiguration der Partitionierung des Flash-Speichers im ESP32 nicht optimal war. Im ESP ist standardmäßig eine Partitionierung mit 1MB Flash-Speicher für das Binary vorgesehen. Diese Partitionierung ist für die meisten Anwendungsfälle ausreichend, jedoch nicht für dieses Projekt. Die Partitionierung kann jedoch über den Befehl \textit{idf.py menuconfig} und dem sich öffnenden Konfigurationsassistenten angepasst werden.

\begin{figure}[H]
    \centering

    \begin{subfigure}[b]{0.40\textwidth}
        \centering
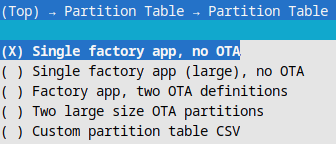
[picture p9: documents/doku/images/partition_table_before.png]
        
        \caption{Vor Optimierung}
        \label{fig:partition_table_before}
    \end{subfigure}
    \hspace{0.05\textwidth} % Adjust this value as needed
    \begin{subfigure}[b]{0.40\textwidth}
        \centering
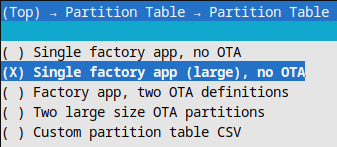
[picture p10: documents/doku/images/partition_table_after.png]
        
        \caption{Nach Optimierung}
        \label{fig:partition_table_after}
    \end{subfigure}

    \caption{Partitionierung des Flash-Speichers vor und nach der Optimierung}
    \label{fig:partition_table}
\end{figure}

Abbildung \ref{fig:partition_table} zeigt die Partitionierung des Flash-Speichers vor und nach der Optimierung. OTA steht dabei für Over-the-Air Updates. Diese wurden in diesem Projekt nicht berücksichtigt, weshalb kein Speicher dafür reserviert werden musste. \newline

Das Problem konnte letztendlich dadurch behoben werden, dass anstatt der normalen App-Größe nun die \textit{Large}-Variante verwendet wurde. In dieser Konfiguration werden ca. 1,5 MB für die App zur Verfügung gestellt. Die Auslastung des Speichers sah danach identisch wie in Abbildung~\ref{fig:memory_size_before} aus, jedoch wurde der Fehler nicht mehr angezeigt. Insgesamt benötigt die Binary nun 82 \% des verfügbaren Speichers, was für den ESP32 eine akzeptable Auslastung in Anbetracht der implementierten Komponenten darstellt. \newline

\begin{figure}[H]
    \centering
    
    \caption{Freier Speicher nach der Optimierung}
    \label{fig:memory_size_after}
\end{figure}

Die Initialisierung des WiFi-Stacks und des MQTT-Stacks sind in der main-Funktion des Programms implementiert. Dabei wird der WiFi-Stack zuerst initialisiert, um eine Verbindung zum WLAN-Netzwerk herzustellen. Anschließend wird der MQTT-Stack mit allen notwendigen Parametern, wie beispielsweise der IP-Adresse des MQTT-Brokers, geladen. Auch dieser Integrationsschritt wurde durch paralleles Logging in der Konsole begleitet. Die Verbindungsversuche zum Netzwerk verliefen durchwegs positiv. Ausgenommen von Spitzen der Latenz, die durch die Übertragung der Daten bei mehreren Teilnehmern über das WLAN-Netzwerk verursacht wurden. Sollte es zu einem Verbindungsabbruch kommen, soll in erster Linie versucht werden, die Verbindung automatisch wiederherzustellen. Dies gelang meistens auch, jedoch kam es in seltenen Fällen zu einem Timeout, der nicht automatisch behoben werden konnte. In diesem Fall wurde der ESP32 neu gestartet. \newline

Erste Armbewegungen konnten ohne Fahrzeug durchgeführt werden. Dabei wurde abermals auf \textit{mosquitto} als MQTT-Broker auf dem Arbeitsrechner zurückgegriffen. Zu diesem Zeitpunkt war die Implementierung des Objekttrackings noch nicht abgeschlossen, weshalb die Nachrichten noch manuell gesendet werden mussten. Feste Winkelpositionen konnten nach manueller Anpassung erfolgreich an den Topic \textit{vehicle/turret/cmd} gesendet werden. Die Fahrzeugsteuerung konnte die Nachrichten korrekt empfangen und die Plattform entsprechend bewegen. Diese Integration ermöglichte nun für den weiteren Verlauf des Projekts, dass zukünftig die KI-Komponente die Plattform steuert. Die konkrete Umsetzung des Objekttrackings wird im Abschnitt~\ref{sec:objekttracking} beschrieben. \newline

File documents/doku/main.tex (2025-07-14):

\documentclass[a4paper,11pt]{report}

% Packages
\usepackage[utf8]{inputenc}
\usepackage[T1]{fontenc}
\usepackage[ngerman]{babel} % For German language
\usepackage{graphicx}
\usepackage{amsmath}
\usepackage{amsfonts}
\usepackage{amssymb}
\usepackage{hyperref}
\usepackage{listings} % For code listings
\usepackage{setspace} % For line spacing
\usepackage{geometry} % For setting margins
\usepackage{titlesec} % For customizing title formats
\usepackage{chngcntr} % For changing counter settings
\usepackage{fancyhdr} % For custom headers and footers
\usepackage[style=ieee,backend=biber,url=true,citestyle=numeric-comp]{biblatex}
\addbibresource{references.bib}
% Remove empty parenthesis if no date specified 
\DeclareFieldFormat{parens}{%
  \iffieldundef{year}{}{\mkbibparens{#1}}%
}
\DeclareFieldFormat{date}{%
  \iffieldundef{year}{n.d.}{#1}%
}

\usepackage{float}
\usepackage{titling}
\usepackage{svg}
\usepackage{pdfpages}
\usepackage{array}
\usepackage{acro}
\usepackage{csquotes}
\usepackage{url}
\usepackage{breakurl}
\usepackage[export]{adjustbox}
\usepackage{booktabs}
\usepackage{longtable}
%\newcolumntype{P}[1]{>{\raggedright\arraybackslash}p{#1}}
\usepackage{tabularx}  % Automatically adjusts table width
\usepackage{hyperref}
\usepackage{subcaption}
\usepackage{xcolor}
\usepackage{siunitx}
\usepackage{listings}
\usepackage{dirtree}
\usepackage{textgreek}

\lstdefinelanguage{json}{
    morestring=[b]",
    morecomment=[l]{//},
    morekeywords={true, false, null},
    sensitive=false,
}

\lstset{
    language=json,
    backgroundcolor=\color{gray!10},
    basicstyle=\ttfamily\small,
    keywordstyle=\color{blue},
    stringstyle=\color{orange},
    commentstyle=\color{gray},
    showstringspaces=false,
    breaklines=true
}

% Margins
\geometry{
    left=3cm,
    right=2.5cm,
    top=2.5cm,
    bottom=2.5cm
}

% Line spacing
\onehalfspacing % 1.5 line spacing, you can use \singlespacing for single line spacing

% Remove ident before newline
\setlength{\parindent}{0pt}

% Decimal numbering without "Kapitel" prefix
\titleformat{\chapter}[block]
  {\normalfont\huge\bfseries}{\thechapter.}{20pt}{\Large}
\titleformat{\section}
  {\normalfont\Large\bfseries}{\thesection.}{1em}{}
\titleformat{\subsection}
  {\normalfont\large\bfseries}{\thesubsection.}{1em}{}
\titleformat{\subsubsection}
  {\normalfont\normalsize\bfseries}{\thesubsubsection.}{1em}{}

% Custom headers
\pagestyle{fancy}
\fancyhf{}
\fancyhead[L]{\leftmark}    % Left side of the header
\fancyfoot[C]{\thepage}     % Mid side of the footer

% Redefine \leftmark to show only the chapter number and title
\renewcommand{\chaptermark}[1]{\markboth{\thechapter.\ #1}{}}

% \input{acronyms.tex}

\begin{document}

% Title Page
\input{src/shared/cover.tex}

% Table of Contents
\tableofcontents
\newpage

% Main Content
\input{src/wohlrab/projektplanung.tex}

\input{src/wohlrab/vorbereitungen.tex}

\input{src/koch/stromversorgung.tex}
\input{src/wohlrab/stromversorgung.tex}

\input{src/specht/cad.tex}
\input{src/becker/cad.tex}

\input{src/becker/esp32.tex}
\input{src/specht/esp32.tex}

\input{src/becker/raspberry.tex}
\input{src/wohlrab/i2c.tex}
\input{src/koch/raspberry.tex}
\input{src/wohlrab/ultraschall.tex}

\input{src/juergens/ai_model.tex}
\input{src/juergens/webrtc.tex}
\input{src/juergens/objekttracking.tex}

\input{src/koch/webserver.tex}
%\input{gnn}
%\input{p5p}
%\input{end.tex}

% Time tables
\includepdf[pages=-]{pdfs/Stundenliste_Fabian_Becker.pdf}
\includepdf[pages=-]{pdfs/Stundenliste_Nicolas_Koch.pdf}
\includepdf[pages=-]{pdfs/Stundenliste_Jendrik_Juergens.pdf}
\includepdf[pages=-]{pdfs/Stundenliste_Michael_Specht.pdf}
\includepdf[pages=-]{pdfs/Stundenliste_Jonathan_Wohlrab.pdf}

% List of Figures
\listoffigures
\addcontentsline{toc}{chapter}{Abbildungsverzeichnis}
\newpage

% List of Tables
%\listoftables
%\addcontentsline{toc}{chapter}{Tabellenverzeichnis}
%\newpage

% List of Acronyms
%\addcontentsline{toc}{chapter}{Abkürzungen}
% \printacronyms[heading=chapter*]
%\newpage

% Bibliography
\newpage
\begin{sloppypar}
  \addcontentsline{toc}{chapter}{Literaturverzeichnis} % Add to ToC
  \printbibliography[title=Literaturverzeichnis]
\end{sloppypar}

% Annex
% \input{annex.tex}

\end{document}

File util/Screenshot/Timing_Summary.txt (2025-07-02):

=== Timing Summary - CUDA===
Processed 293 frames
Total elapsed time (real-time): 8.22s
Total inference time: 5.27s
Overhead time (display, I/O, etc.): 2.95s
Average FPS (inference only): 55.61
Average FPS (real-time): 35.65

=== Timing Summary - RPI5 ===
Processed 293 frames
Total elapsed time (real-time): 77.55s
Total inference time: 76.87s
Overhead time (display, I/O, etc.): 0.68s
Average FPS (inference only): 3.81
Average FPS (real-time): 3.78

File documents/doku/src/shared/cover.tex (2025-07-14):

\begin{titlepage}
    \begin{flushleft}
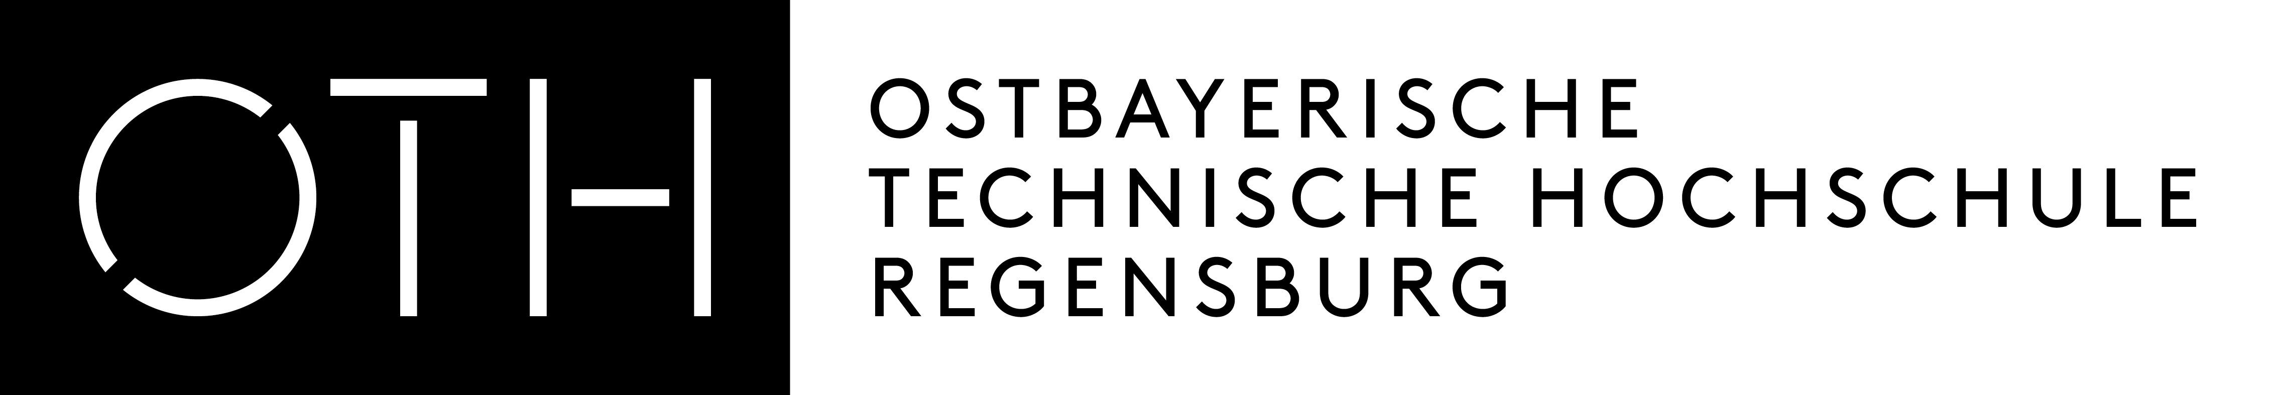
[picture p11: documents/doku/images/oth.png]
        
    \end{flushleft}

    \vspace*{2cm}

    \centering
    {\scshape\Large Datenverarbeitung in der Technik \par}
    \vspace{0.5cm}
    {\scshape Sommersemester 2025 \par}
    \vspace{0.5cm}
    {\huge\bfseries Projektbericht \par}
    \vspace{3cm}

    \begin{flushleft}
        \large
        \textbf{Teammitglieder:} \\
        \vspace{0.5cm}

        Fabian Becker\hfill \\[0.5cm]
        Jendrik Jürgens\hfill \\[0.5cm]
        Nicolas Koch\hfill \\[0.5cm]
        Michael Specht\hfill \\[0.5cm]
        Jonathan Wohlrab\hfill \\[1cm]

        \textbf{Betreuung:} \\
        Prof. Dr. Alexander Metzner, Matthias Altmann \\
        \vspace{0.5cm}

        \textbf{Abgabedatum:} \\
        15.07.2025 \\
    \end{flushleft}

    \vfill
    \centering
    {\large \today\par}
\end{titlepage}

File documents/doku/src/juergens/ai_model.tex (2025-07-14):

\chapter{Erstellung \& Ausführung eines KI-Modells zur Objektdetektion} \label{sec:ai_model}
\section{Anforderungen an das KI-Modell (Jürgens)}
Ziel dieser Teilaufgabe war die Entwicklung eines KI-Modells zur automatischen Erkennung eines Holzfliegers als Zielobjekt. Eine zentrale Anforderung bestand darin, das Modell lokal auf einem Raspberry Pi 5 zu implementieren und auch dort auszuführen. Aufgrund der fehlenden dedizierten Grafikkarte des Systems war ein leichtgewichtiges, CPU-optimiertes Modell erforderlich. Der verwendete Raspberry Pi 5 verfügt über einen 64-Bit Quad-Core ARM Cortex-A76 Prozessor und 8 GB Arbeitsspeicher. \cite{raspberrypi5website} 
Aufgrund dieser Hardwarebeschränkung und persönlicher Erfahrungen wurde entschieden, dass ein YOLO Modell des Unternehmens Ultralytics verwendet wird. Dieses hat sich auf state-of-the-art KI-Modelle der YOLO-Familie im Bereich der Objekterkennung und Bildsegmentierung spezialisiert. \cite{ultralyticsFAQ} Die Modelle von Ultralytics zeichnen sich durch eine hohe Präzision und schnelle Inferenzzeiten aus. Diese Eigenschaften sind für die lokale Ausführung auf dem Raspberry Pi 5 von großer Bedeutung, da hier die Inferenz auf der CPU durchgeführt werden muss. 
Besonders interessant sind die Open-Source Implementierungen der YOLOv8 und YOLOv11 Modelle. Diese sind bereits vortrainiert und haben bestehende Gewichte und bieten somit die Möglichkeit direkt verwendet oder auf einem eigenen Datensatz weitertrainiert zu werden. Ein weiterer Vorteil der YOLO Modelle und Ultralytics liegt in der sehr guten Dokumentation und einer geringen Einstiegshürde. Mit der Ultralytics Python Bibliothek können Modelle einfach erstellt, trainiert und evaluiert werden. Dies bildet die Grundlage für die Entwicklung und Verwendung des Modells in diesem Projekt.

\section{Modellauswahl (Jürgens)}
Die YOLOv8 und YOLOv11 Modelle von Ultralytics werden in verschiedenen Größen angeboten. Mit steigender Größe des Modells steigt zwar die Genauigkeit des Modells, aber auch die Inferenzzeit und der Speicherbedarf.
Die Modelle werden in folgenden Größen angeboten:
\begin{itemize}
  \item YOLOv8/11n - Nano 
  \item YOLOv8/11s - Small
  \item YOLOv8/11m - Medium
  \item YOLOv8/11l - Large
  \item YOLOv8/11x - Extra Large
\end{itemize}
Die Modellauswahl ist durch die Hardware des Raspberry Pi 5 begrenzt. So sind insbesondere die mittleren und großen Modelle aufgrund der hohen Inferenzzeiten nicht für die Ausführung auf der CPU des Raspberry Pi 5 geeignet. Bereits das YOLOv8m Modell hat eine Inferenzzeit von 234,7 ms. \cite{ultralyticsYOLOv8Performance} Aufgrund dessen wurde entschieden, dass eine Beschränkung auf die kleineren Modelle YOLOv8n, YOLOv8s, YOLO11n und YOLO11s sinnvoll ist. Diese Modelle haben eine geringere Inferenzzeit und könnten somit besser für die Ausführung auf dem Raspberry Pi 5 geeignet sein. 
Die folgenden Leistungsmetriken stammen aus der offiziellen Online-Dokumentation von Ultralytics [\cite{yolov8_ultralytics,ultralyticsYOLOv8Performance,yolo11_ultralytics}]:
\begin{itemize}
  \item YOLOv8n $\approx$ 80.4 ms
  \item YOLOv8s $\approx$ 128.4 ms
  \item YOLO11n $\approx$ 56.1 ms 
  \item YOLO11s $\approx$ 90.0 ms 
\end{itemize}

Anhand dieser Werte und persönlicher Erfahrungen wurde zunächst entschieden, dass das YOLOv8n Modell im ONNX-Format verwendet wird. Dieses Modell hat mit einer Inferenzzeit von 80,4 ms eine vertretbare Geschwindigkeit.

\subsection{Das ONNX-Format (Jürgens)}
ONNX steht für Open Neural Network Exchange und stellt ein Open-Source-Format für KI-Modelle bereit. Es ermöglicht KI-Modelle über verschiedene Frameworks und Plattformen hinweg zu verwenden. Modelle können beispielweise in einem Framework mit PyTorch trainiert und anschließend in das ONNX-Format exportiert werden. Oftmals ermöglicht die Verwendung des ONNX-Formats eine bessere Performance von KI-Modellen auf verschiedenen Hardwareplattformen durch optimierte Inferenzmaschinen. \cite{ultralyticsGlossaryONNX}

Der Ansatz für dieses Projekt war es, ein Modell auf einer leistungsstarken Maschine mit dedizierter Grafikkarte zu trainieren und dieses anschließend in das ONNX-Format zu exportieren. Die Python Bibliothek von Ultralytics bietet unter Anderem die Möglichkeit ein Modell zu trainieren und anschließend in das ONNX-Format zu exportieren. Nach dem Training liegt das Modell zunächst im PyTorch-Format mit der Dateiendung \texttt{.pt}.
Nach dem Export in das ONNX-Format hat das Modell die Dateiendung \texttt{.onnx}. Dieses Format kann beispielsweise mit Tools wie NVIDIA TensorRT oder Intels OpenVINO optimiert werden. Laufzeitumgebungen wie ONNX Runtime sind dabei für Hochleistungsinferenz über verschiedene Hardware optimiert. \cite{ultralyticsGlossaryONNX}

\section{Trainingsdaten \& Annotation (Jürgens)}
Die Qualität und Performance eines KI-Modells hängt maßgeblich von der Qualität der Trainingsdaten ab. Der erste Schritt ist es, einen qualitativ hochwertigen Datensatz zum Trainieren des Modells zu erstellen. Das Ziel ist es endgültig einen Holzflieger auf einem Bild zu erkennen. Die Trainingsbilder wurden direkt mit dem Raspberry Camera Module 3 aufgenommen, welches mit einer Auflösung von 11,9 Megapixeln, einer Bittiefe von 24 Bit und einer Bildgröße von 4608x2592 Pixeln arbeitet. \cite{raspberrypi5cammodule3} Die Kamera wird neben der Erstellung der Trainingsdaten auch für die Inferenz des Modells im späteren Verlauf verwendet. 
Um eine robuste Objekterkennung unabhängig von der räumlichen Orientierung des Zielobjekts zu gewährleisten, wurde ein Datensatz von 1.201 Bildern erstellt. Diese umfassen verschiedene Umgebungsbedingungen, Beleuchtungssituationen und Perspektiven, wobei das Zielobjekt in nahezu allen möglichen Neigungen erfasst wurde.
Für das überwachte Lernverfahren sind neben den Bilddaten entsprechende Annotationen erforderlich. Der Annotationsprozess erfordert die manuelle Markierung der zu erkennenden Objekte in einem geeigneten Tool sowie deren Konvertierung in ein kompatibles Format. Dieser arbeitsintensive Prozess ist von entscheidender Bedeutung, da die Qualität der Annotationen direkt die Modellperformanz beeinflusst. Vor Beginn des Annotationsprozesses muss zunächst die Art der Annoation definiert werden.
Für diese Arbeit gab es zwei Arten der Annotation, die in Betracht gezogen wurden:
\begin{itemize}
  \item Bounding Box: Ein Rechteck wird um das zu erkennende Objekt gezeichnet. Diese Methode ist einfach und schnell, aber weniger präzise.
  \item Polygon: Eine komplexere Form wird um das Objekt gezeichnet. Diese Methode ist genauer, aber auch zeitaufwändiger.
\end{itemize}
Die Entscheidung fiel auf die zeitaufwändigere Polygon-Annotation. Diese ermöglicht eine genauere Erkennung des Holzfliegers weil nicht nur die äußeren Kanten sondern, auch die komplexere Form des Objekts berücksichtigt wird. 
Neben der speziellen Form des Holzfliegers war diese Entscheidung auch durch die relativ geringe Anzahl vorhandener Trainingsbilder begründet. 
Zur Annotation wurde das Open-Source Tool LabelStudio verwendet. Dieses bietet eine benutzerfreundliche Oberfläche und lässt sich sehr genau personalisieren. Durch die integrierte Projektverwaltung und verschiedene unterstützte Exportformate bietet das Tool eine gute Lösung für das Labeling.
Aufgrund fehlender Implementation der Exportfunktion für größere Datensätze (Export von Bildern und korrespondierenden Annotationen) war eine Nachbereitung des Datensatzes notwendig. Nach Abschluss der Annotation wurden die Labels im YOLO-Format exportiert und eine Ordnerstruktur erstellt, die zum Training des YOLO-Modells verwendet werden kann.
\\ Folgende Ordnerstruktur wurde erstellt: \\ 

\dirtree{%
.1 train/.
.2 images/.
.2 labels/.
.1 val/.
.2 images/.
.2 labels/.
.1 test/.
.2 images/.
.2 labels/.
}

\newpage
Die Bilder und Labels im Ordner \texttt{train} werden für das Training des Modells verwendet, die Bilder und Labels im Ordner \texttt{val} für die Validierung des Modells während des Trainings und die Bilder und Labels im Ordner \texttt{test} für die abschließende Evaluation des Modells.
Die Bilder wurden in den Ordnern \texttt{images} und die Annotationen in den Ordnern \texttt{labels} gespeichert. Die Annotationen werden in Textdateien mit der Endung \texttt{.txt} gespeichert, wobei jede Textdatei die gleiche Bezeichnung wie das zugehörige Bild hat. Beispielsweise wird das Bild \texttt{image1.jpg} im Ordner \texttt{images} durch die Textdatei \texttt{image1.txt} im Ordner \texttt{labels} annotiert.

\section{Training des Modells (Jürgens)}
Ultralytics bietet mit der Python-Bibliothek \texttt{ultralytics} eine einfache Möglichkeit, ein YOLO-Modell zu trainieren, zu validieren und zu evaluieren. Vor dem Training wird eine Konfigurationsdatei benötigt, welche die Pfade des Trainingsordners, des Validierungsordners und des Testordner enthält. Neben den Pfaden beinhaltet Sie noch die Anzahl der Klassen und die dazugehörigen Namen. In diesem Fall gibt es nur den Holzflieger als Klasse, welcher zukünftig mit der Bezeichnung 'Plane' gelabelt wird. 
\\

Das Training erfolgt auf einer Mittelklasse NVIDIA Grafikkarte (RTX 3070) mit 8 GB Grafikkartenspeicher. Die Produktdaten wurden der offiziellen NVIDIA Produktseite entnommen.\cite{RTX3070Specs} Während des Trainings werden die Trainingsbilder augmentiert um die Robustheit des Modells zu erhöhen. So werden verschiedene Transformationen auf die Bilder angewendet, wie z.B. Rotation, Skalierung oder Änderung der Helligkeit. Hiermit wird die Varianz der Trainingsbilder künstlich erhöht, was zu einer besseren Performance des Modells führt. \cite{YoloDataAugmentation} Durch das Verwenden von vortrainierten Gewichten wird die Trainingszeit verkürzt und die Performance des Modells verbessert. Diese Gewichte werden vor dem Training als \texttt{.pt} Datei heruntergeladen und bilden den Ausgangspunkt für das Training. Durch Transferlearning, also dem Weitertrainieren eines vortrainierten Modells auf einen neuen Datensatz, kann die Performance des Modells weiter verbessert werden. Zudem wird die benötigte Trainingszeit reduziert. \cite{TransferLearningGlossary}

Nach Abschluss des Trainings werden automatisch die besten Gewichte des Modells unter \texttt{runs/detect/train/weights/best.pt} gespeichert. Neben den reinen Gewichten erstellt das Trainingsskript unter anderem die Datei \texttt{results.png} in welcher verschiedene Metriken über den Trainingsfortschritt, wie zum Beispiel die \texttt{mAP50} und \texttt{mAP50-95}, visualisiert werden. Die Metrik \texttt{mean Average Precision} wie zum Beispiel \texttt{mAP50} und \texttt{mAP50-95} geben die Genauigkeit des Modells an, wobei \texttt{mAP50} die Genauigkeit bei einer IoU-Grenze von 0,5 und \texttt{mAP50-95} bei IoU-Werten zwischen 0,5 und 0,95 angibt \cite{MAPGlossary}. IoU steht für Intersection over Union und gibt die prozentuale Schnittmenge zwischen der vorhergesagten Bounding Box und der tatsächlichen Bounding Box an.\cite{IOUGlossary}
So kann man sagen, dass ein hoher \texttt{mAP50}-Wert und \texttt{mAP50-95}-Wert gute Indikatoren sind wie gut das Modell die Objekte erkennt. \newpage

\begin{figure}[h]
\centering
\begin{subfigure}[b]{0.45\textwidth}
  \centering
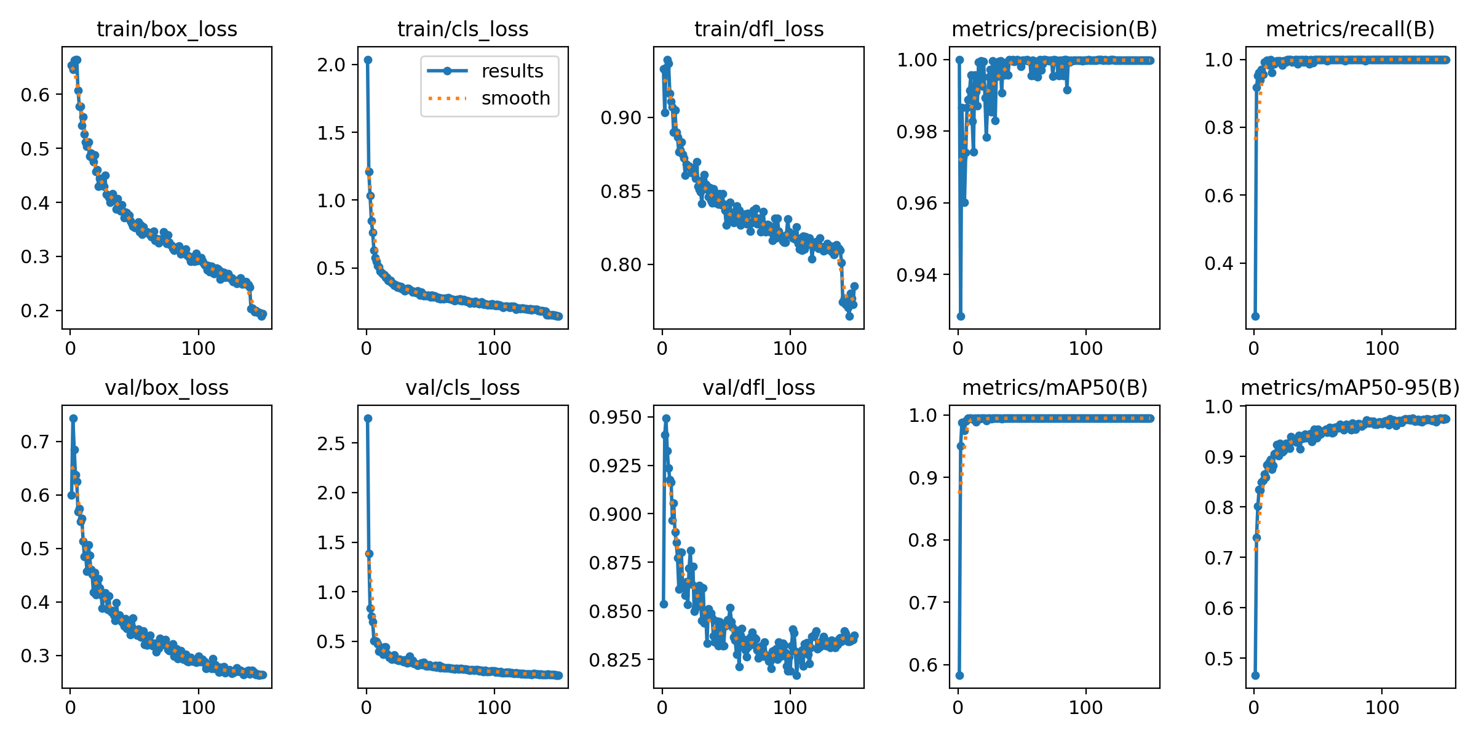
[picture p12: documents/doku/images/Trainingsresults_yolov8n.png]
  
  \caption{YOLOv8n}
  \label{fig:Trainingsresultate yolov8n}
\end{subfigure}
\hfill
\begin{subfigure}[b]{0.45\textwidth}
  \centering
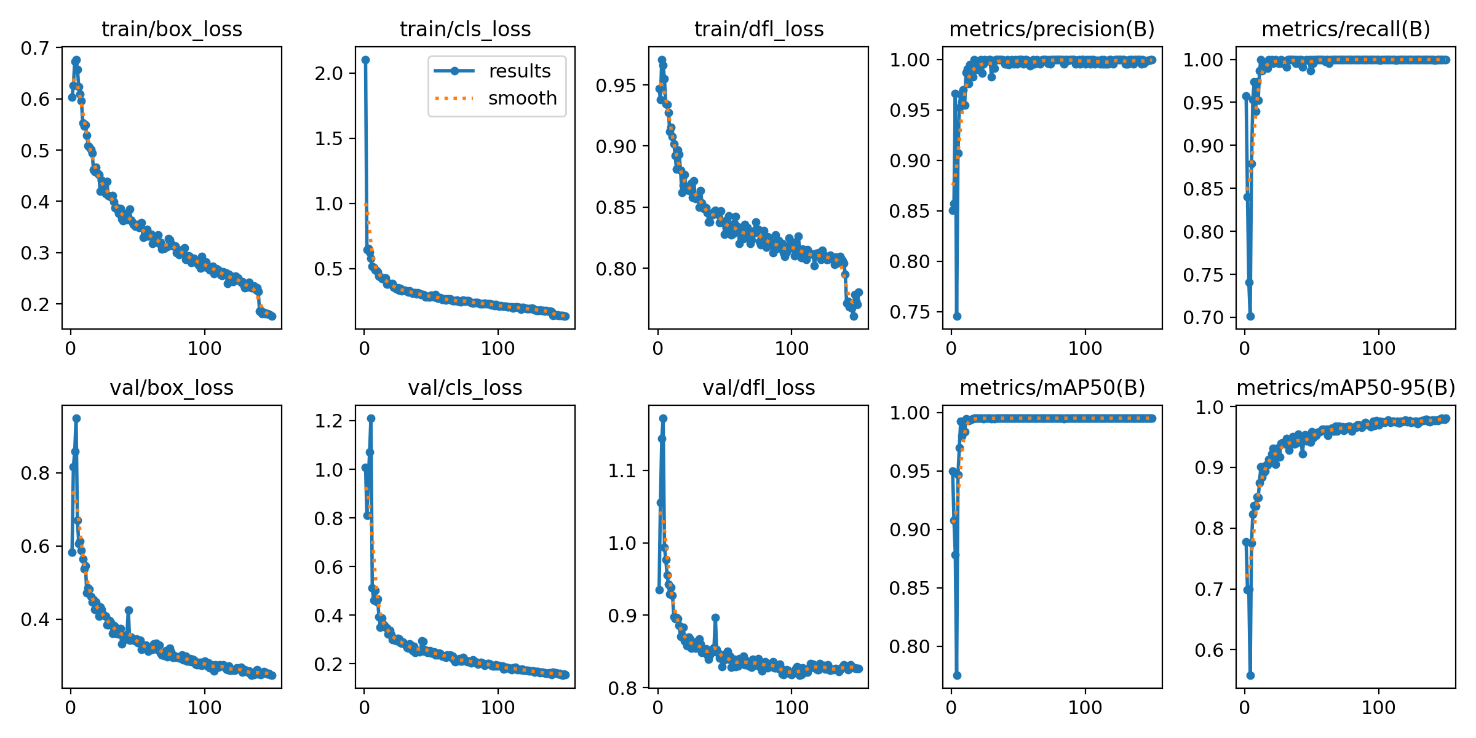
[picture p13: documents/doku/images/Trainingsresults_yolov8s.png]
  
  \caption{YOLOv8s}
  \label{fig:Trainingsresultate yolov8s}
\end{subfigure}
\vskip\baselineskip
\begin{subfigure}[b]{0.45\textwidth}
  \centering
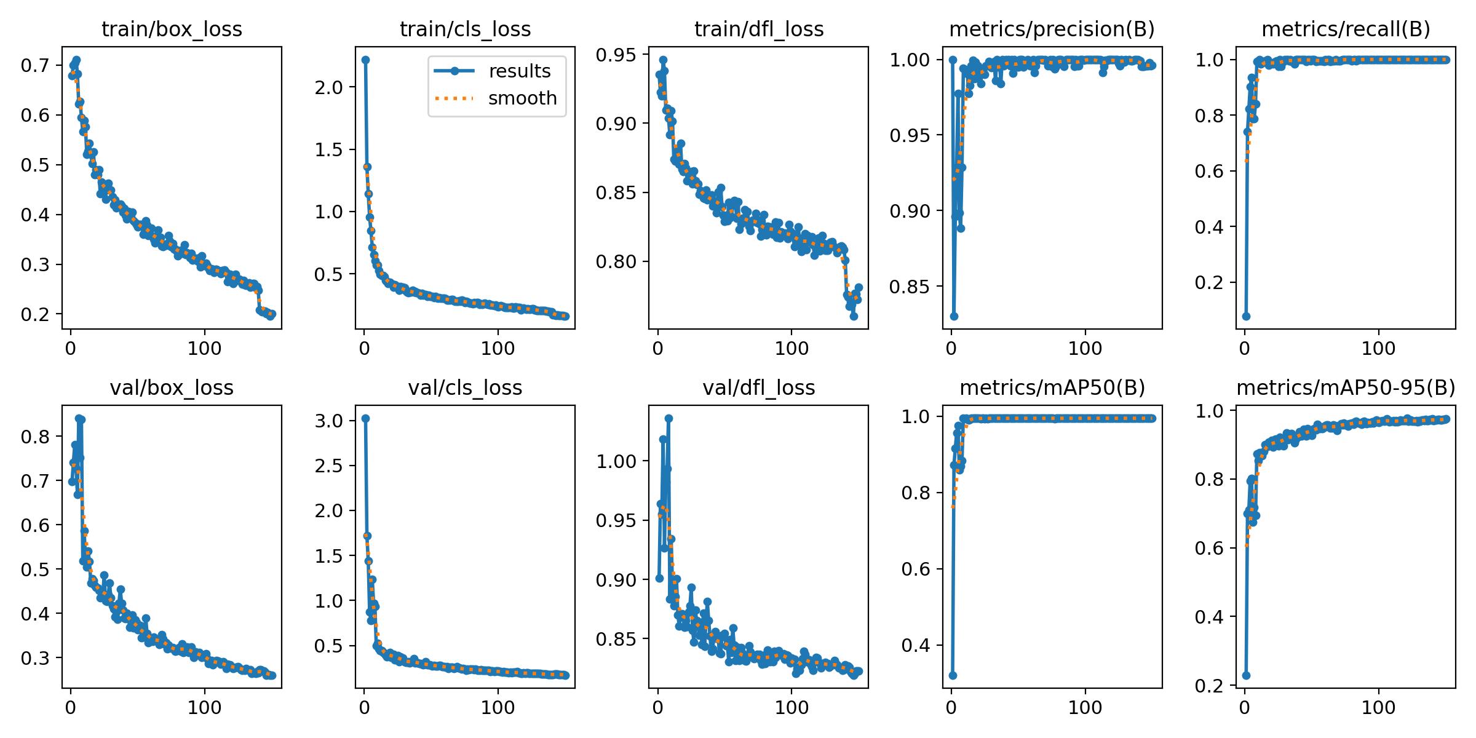
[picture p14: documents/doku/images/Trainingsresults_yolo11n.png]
  
  \caption{YOLO11n}
  \label{fig:Trainingsresultate yolo11n}
\end{subfigure}
\hfill
\begin{subfigure}[b]{0.45\textwidth}
  \centering
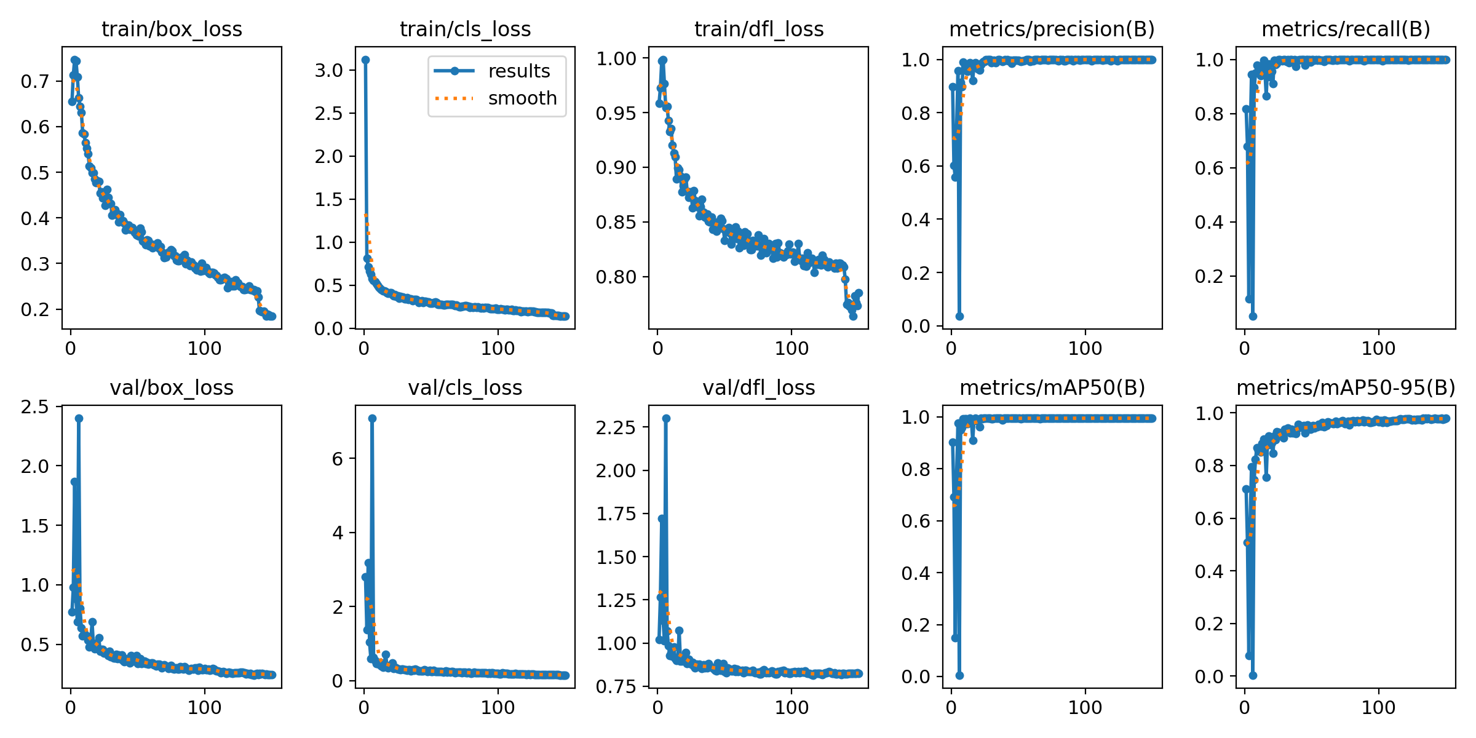
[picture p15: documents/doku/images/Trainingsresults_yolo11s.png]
  
  \caption{YOLO11s}
  \label{fig:Trainingsresultate yolo11s}
\end{subfigure}
\caption{Vergleich Trainingsresultate YOLOv8n, YOLOv8s, YOLO11n und YOLO11s}
\label{tab:Vergleich Trainingsresultate}
\end{figure}

Wie in \ref{tab:Vergleich Trainingsresultate} zu sehen ist, schneiden alle Modelle nach der Trainingsphase von 150 Epochen ähnlich gut ab. Eine Epoche stellt dabei einen vollständigen Durchlauf durch den gesamten Trainingsdatensatz dar.\cite{EpochGlossary} Anhand dieser Resultate wurde zunächst das YOLOv8n Modell ausgewählt, da es entsprechend der Trainingsmetriken trotz der geringeren Größe im Vergleich zu den s-Modellen eine ähnlich gute Performance aufweist dabei aber eine geringe Inferenzzeit aufweist. Dazu kommen positive persönliche Erfahrungen mit diesem Modell. 

Um das Modell schließlich auch als ONNX-Modell zu betreiben muss dieses zunächst in das ONNX-Format exportiert werden. Der Export erfolgt mit der Ultralytics Python-Bibliothek.

\section{Ausführung des Modells im ONNX-Format (Jürgens)}
Um generell ein KI-Modell im ONNX-Format auszuführen, sind einige Voraussetzung an das System zu erfüllen. Es werden verschiedene Programme und Bibliotheken benötigt, um das Modell auszuführen. Um schnelle Ergebnisse und erstes Feedback zu erhalten wie die Inferenz des Modells im ONNX-Format abläuft wurde zunächst eine Laufzeitumgebung auf dem persönlichen Computer eingerichtet. Folgende Bibliotheken und Programme waren auf jeden Fall notwendig, um das Modell in einer Windows-Umgebung auszuführen:

\begin{itemize}
  \item ONNX Runtime v1.21.0
  \item OpenCV (mit GStreamer Unterstützung)
  \item CUDA 12.6 (optional, für GPU-Beschleunigung, NVCC Compiler erforderlich)
  \item cuDNN 9.9 (NVIDIA Deep Neural Network library, NVIDIA Developer Account erforderlich)
\end{itemize}

\newpage
Zwischen diesen Komponenten gibt es Abhängigkeiten speziell in der Versionierung. So muss beispielsweise die CUDA-Version zur eingesetzten Grafikkarte und die cuDNN-Version zur CUDA-Version passen. \\ Um den Anforderungen einer minimalen Laufzeit pro Inferenz gerecht zu werden, wurde C++ als Zielprogrammiersprache gewählt. Aufgrund fehlender Erfahrungen mit KI-Modellen im ONNX-Format wurde die Erstellung eines ersten Prototypen mit Hilfe von KI-Assistenten und der ONNX-Dokumentation gelöst. Es stellte sich heraus, dass die Ergebnisse der Inferenz im ONNX-Format mangelhaft sind, wobei man eine fehlerhafte Implementierung im C/C++ Code nicht ausschließen kann. Im Vergleich zu den Ergebnissen der Inferenz mit der von Ultralytics bereitgestellten Python-Bibliothek kann man die Ergebnisse der Inferenz des C/C++ Prototypen nicht verwenden. Um ein vergleichbares Ergbnis zu produzieren, werden beide Inferenzen mit dem selben Video getestet. Das Video wurde direkt mit dem Raspberry Pi 5 und dem Camera Module 3 aufgenommen.

\begin{figure}[h]
\centering
\begin{subfigure}[b]{0.48\textwidth}
  \centering
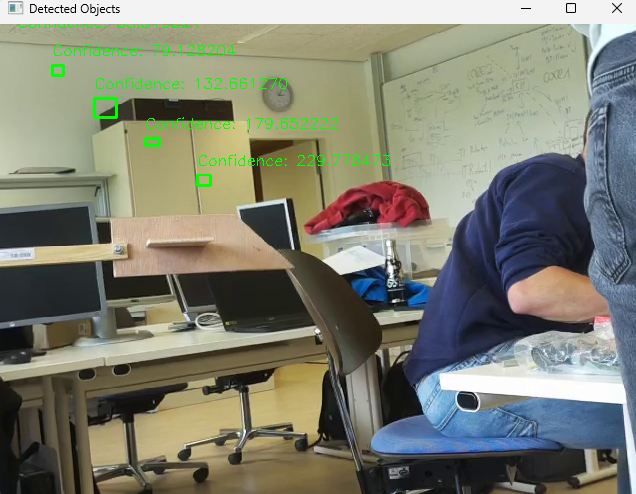
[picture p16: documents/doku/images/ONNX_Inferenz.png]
  
  \caption{Inferenz im ONNX-Format mit C++ Prototypen}
  \label{fig:Screenshot: Inferenz im ONNX-Format mit C++ Prototypen}
\end{subfigure}
\hfill
\begin{subfigure}[b]{0.48\textwidth}
  \centering
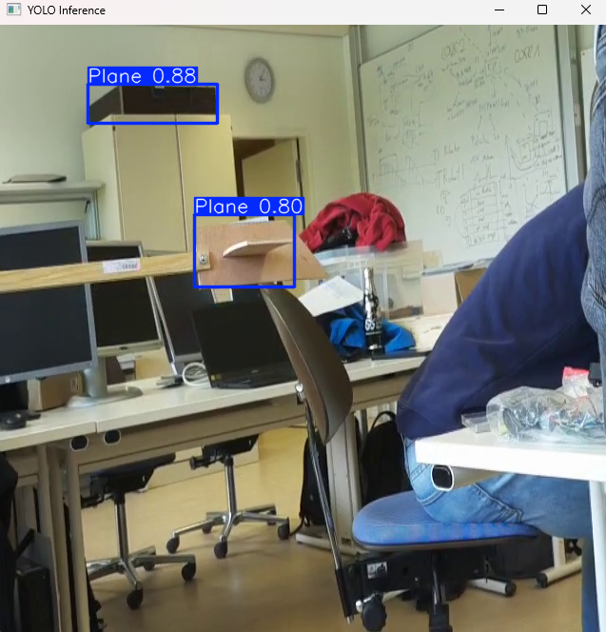
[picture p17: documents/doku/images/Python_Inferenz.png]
  
  \caption{Inferenz in Python mit Ultralytics}
  \label{fig:Screenshot: Inferenz Python mit Ultralytics}
\end{subfigure}
\caption{Vergleich Inferenz ONNX C++ und Python}
\label{tab:Vergleich Inferenz ONNX C++ und Python}
\end{figure}

Wie in \ref{tab:Vergleich Inferenz ONNX C++ und Python} zu sehen ist, sind die Ergebnisse der Inferenz in Python mit der Ultralytics-Bibliothek deutlich besser.
Basierend auf diesen Resultaten wurde entschieden, dass eine weitere Implementierung in C/C++ nicht sinnvoll ist. So fällt besonders die hohe Komplexität, die fehlerhaften Erkennungen, die hohe Einarbeitungszeit hinsichtlich der Projektdauer, aber auch der hohe Aufwand für die Einrichtung einer funktionierenden Laufzeitumgebung ins Gewicht. Mit der Verwendung der Ultralytics-Bibliothek fällt ein Großteil dieser Komplexität weg. 

\section{Inferenz des PyTorch-Modells (Jürgens)}

\subsection{Installation der KI-Abhängigkeiten (Jürgens)} 
Neben der reinen Ultralytics-Bibliothek welche mit einer Reihe weiterer Abhängigkeiten installiert wird, ist besonders die Python-Version von \texttt{OpenCV} von Bedeutung. 
OpenCV ist größtenteils in C++ geschrieben, bietet aber auch eine Python-Schnittstelle an. Diese soll dazu verwendet werden, um auf den Kamera-Stream des Raspberry Pi 5 zuzugreifen. 
In der Regel kann ein Stream in OpenCV mit der Funktion \texttt{cv2.VideoCapture()} geöffnet werden. Der Stream kann dabei eine angebundene Kamera, eine Videodatei oder auch ein RTSP-Stream sein. Aufgrund fehlender Unterstützung des Kamera-Softwarestacks des Raspberry Pi 5 kann die Kamera nicht direkt mit der Funktion \texttt{cv2.VideoCapture()} geöffnet werden \ref{opencvlibcamera}. Der Test mit einer USB-Kamera dagegen funktionierte problemlos. Da OpenCV eine essentielle Abhängigkeit in diesem Projekt ist, wurde ein Workaround gefunden in dem die Kamera des Raspberry Pi 5 mittels GStreamer an OpenCV übergeben wird. Eine reguläre OpenCV-Installation mit dem Python Paketmanager PIP enthält standardmäßig keine GStreamer-Unterstützung. Diese muss explizit aktiviert werden, indem OpenCV aus dem Quellcode mit GStreamer-Unterstützung kompiliert wird. Hierbei ist darauf zu achten, dass nicht nur die GStreamer-Bibliothek korrekt installiert und angegeben wird, sondern auch der Python-Interpreter welcher auf dem Raspberry Pi 5 verwendet wird. Die Kompilierzeit kann dabei mehrere Stunden in Anspruch nehmen und ist abhängig von der Leistung des Systems. So hat die Kompilierung und Installation von OpenCV mit GStreamer-Unterstützung etwa 2 Stunden gedauert. 

\subsection{Erstellung \& Evaluierung der GStreamer-Pipeline (Jürgens)}
Die Video-Pipeline wird insgesamt in zwei Kommunikationspartner aufgeteilt. Der erste Kommunikationspartner bildet eine libcamera-vid-Instanz, welche per Kommandozeile gestartet wird. Diese Instanz öffnet die Kamera des Raspberry Pi 5 und sendet diesen Stream an die eigene IP-Adresse. \\
Der zweite Kommunikationspartner ist der Empfänger des Kamera-Streams. In diesem Fall stellt das Python-Skript mit der OpenCV Installation inklusive GStreamer-Unterstützung den Empfänger dar. Hier wird das trainierte KI-Modell ausgeführt und auf den Stream angewandt.
Bei der Erstellung der Pipelines wird H264 als Video-Codec und UDP als Transportprotokoll gewählt. Mit dieser Kombination soll eine hohe Performance und eine geringe Latenz erreicht werden.\\
Diese Pipeline überträgt den Kamerastream an OpenCV mit einer Latenz von etwa 1 Sekunde. Eine solche Latenz ist für diese Anwendung inakzeptabel, da sowohl die Inferenz des Modells als auch der Kamerastream so nahe wie möglich an der Echtzeit sein soll. Um aber eine Aussage über die Performance des Modells zu erhalten, wurde die Pipeline zunächst mit dieser Latenz getestet.

\subsection{Inferenz des Modells auf dem Raspberry Pi 5 (Jürgens) \label{sec:inference_raspberry}}
Die Inferenz des Modells erfolgt entsprechend der Dokumentation von Ultralytics. Diese wird in einer Endlosschleife durchgeführt und verarbeitet den Kamera-Stream Bild für Bild. Trotz der relativ guten Hardware des Raspberry Pi 5 (im Vergleich zu älteren Raspberry Pi Systemen) ist die Inferenzzeit und damit Nutzbarkeit dieses Ansatz sehr eingeschränkt. So konnte sehr markantes Ruckeln bei der Anzeige des Kamerastreams festgestellt werden. Die Ausführung wirkt sich dabei besonders auf die CPU aus. Wie in \ref{fig:CPU und RAM-Auslastung Inferenz RPI5} dargestellt wurde die CPU vom Raspberry Pi 5 teilweise auf über 90\% ausgelastet. Dieses Verhalten spiegelt sich bei der Performance der KI-Auswertung wieder. So hatte das System trotz der Nutzung des kleinstmöglichen Modells einen sehr geringen Durchsatz (siehe \ref{fig:Zeitanalyse der Inferenz (RPI5)}, grüne Linie). Die Berechnung durch das KI-Modell wurde nach Abstimmung mit Herrn Altmann und dem Team auf einen Laborrechner mit dedizierter Grafikkarte ausgelagert.

\begin{figure}[h]
\centering
\begin{subfigure}[b]{\textwidth}
  \centering
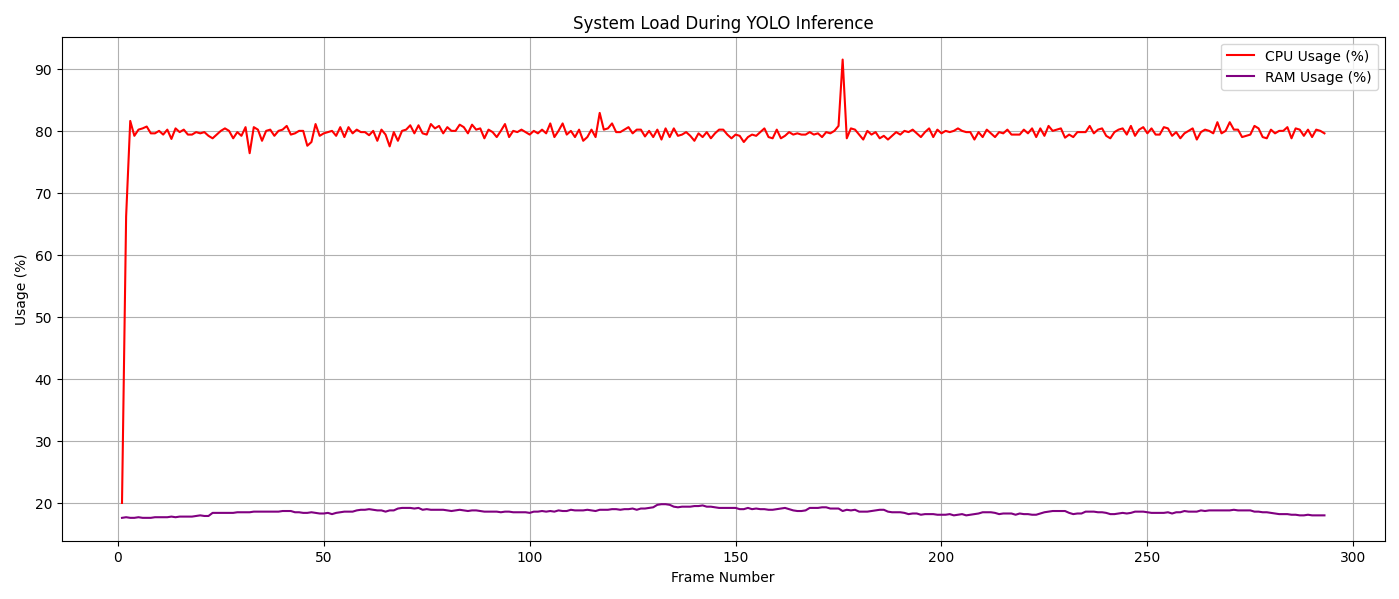
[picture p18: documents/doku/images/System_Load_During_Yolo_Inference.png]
  
  \caption{Systemauslastung während der Inferenz (RPI5)}
  \label{fig:CPU und RAM-Auslastung Inferenz RPI5}
\end{subfigure}
\hfill
\begin{subfigure}[b]{\textwidth}
  \centering
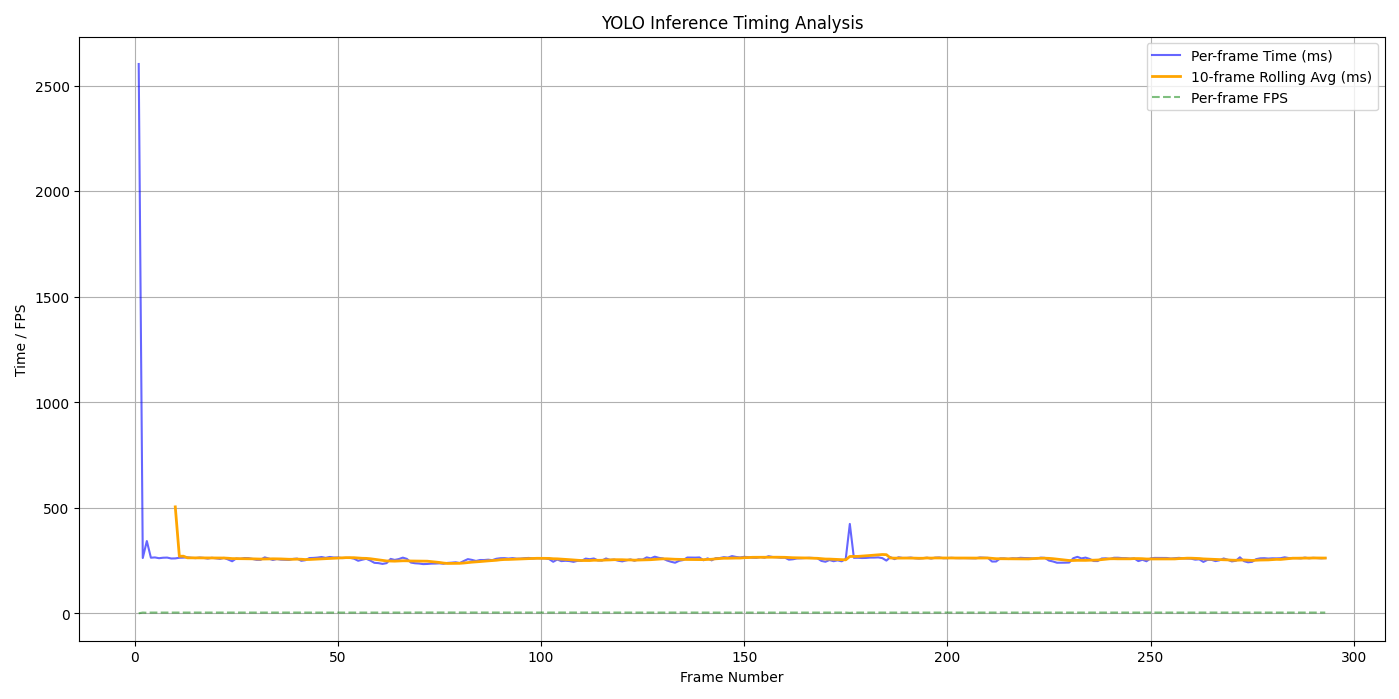
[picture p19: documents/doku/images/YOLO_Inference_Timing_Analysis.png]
  
  \caption{Zeitanalyse der Inferenz (RPI5)}
  \label{fig:Zeitanalyse der Inferenz (RPI5)}
\end{subfigure}
\caption{System- und Zeitanalyse während der Inferenz (RPI5)}
\label{tab:System- und Zeitanalyse waehrend der Inferenz}
\end{figure}
\newpage

\subsection{Inferenz des Modells auf dem Laborrechner (Jürgens)}
Mit dem Plattformwechsel wurde neben der Ausführungsumgebung ebenfalls das verwendete Modell geändert. So wurde das YOLOv8n Modell durch das YOLOv11 Modell ersetzt, welches hinsichtlich der Performance und Genauigkeit eine kleine Verbesserung bietet. Da bei einem Neustart des Laborrechners alle Python Abhängigkeiten neu installiert werden müssen, wurde ein einfaches Batch-Skript erstellt, welches die Installation automatisiert. Hier ist zu beachten, dass Ultralytics standardmäßig eine PyTorch-Version ohne CUDA-Unterstützung installiert. Es ist daher notwendig die mitinstallierten PyTorch-Bibliotheken zu entfernen und anschließend die korrekte Version mit CUDA-Unterstützung zu installieren.
\\
Die Inferenz des Modells auf dem Laborrechner erfolgt also ebenfalls mit der Ultralytics Python-Bibliothek. Anders als auf dem RPI5 läuft die Berechnung des Modells auf der dedizierten Grafikkarte des Laborrechners. Hierbei handelt es sich um eine NVIDIA T1000 Grafikkarte welche die Nutzung von CUDA ermöglicht. Die Inferenzzeit des Modells auf dem Laborrechner fällt mit etwa 8 ms deutlich geringer aus und bietet eine flüssigere Anzeige des annotierten Kamera-Streams (siehe \ref{fig:Timing Zusammenfassung CUDA vs RPI5}). 
\begin{figure}[h]
\centering
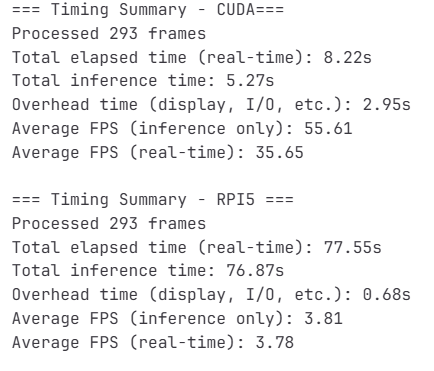
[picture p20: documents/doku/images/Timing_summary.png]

\caption{Timing Zusammenfassung CUDA vs RPI5}
\label{fig:Timing Zusammenfassung CUDA vs RPI5}
\end{figure}
\newpage

Durch die Verwendung der dedizierten Grafikkarte wird nun anstelle der CPU die GPU für die Inferenz verwendet. Dies führt zu einer deutlich geringeren Belastung der CPU des Systems (siehe \ref{tab:CPU und RAM-Auslastung CPU vs CUDA}).

\begin{figure}[h!]
\centering
\begin{subfigure}[b]{\textwidth}
  \centering
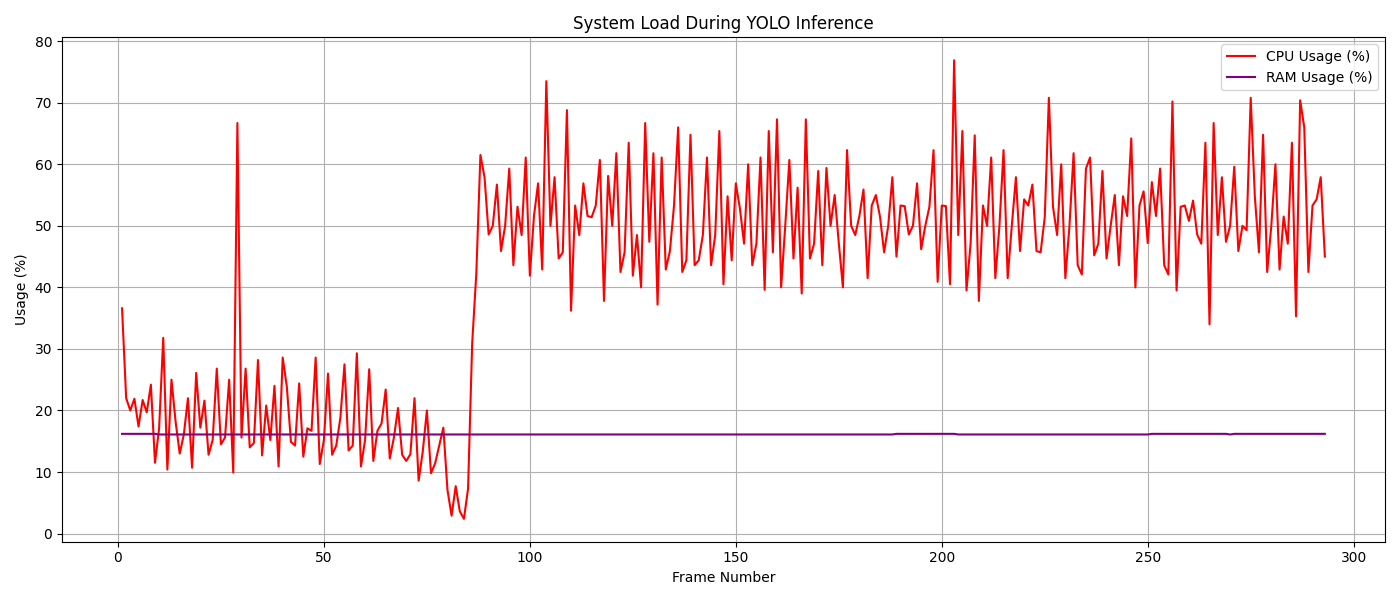
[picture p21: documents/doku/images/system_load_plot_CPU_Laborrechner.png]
  
  \caption{Systemauslastung Laborrechner ohne CUDA}
  \label{fig:CPU und RAM-Auslastung ohne CUDA}
\end{subfigure}
\hfill
\begin{subfigure}[b]{\textwidth}
  \centering
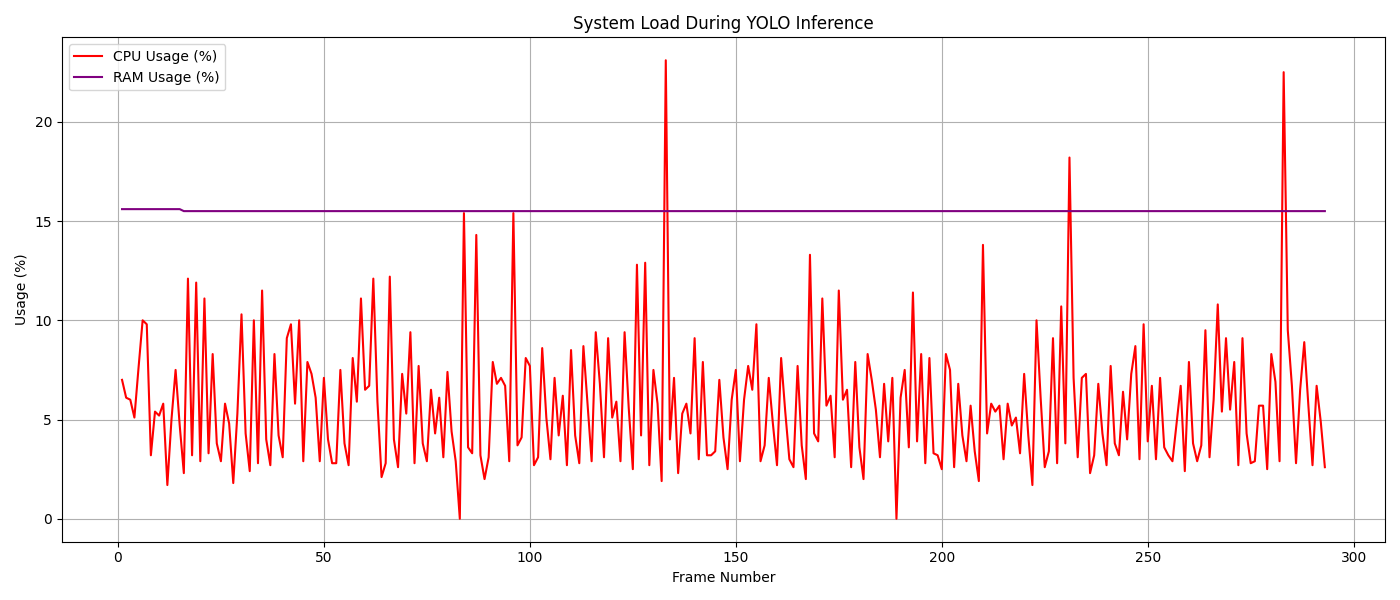
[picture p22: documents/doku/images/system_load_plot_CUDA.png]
  
  \caption{Systemauslastung Laborrechner mit CUDA}
  \label{fig:CPU und RAM-Auslastung mit CUDA}
\end{subfigure}
\caption{Vergleich Inferenz ONNX C++ und Python}
\label{tab:CPU und RAM-Auslastung CPU vs CUDA}
\end{figure}

Der Rückgabewert der Inferenz des Modells beinhaltet unter anderem die Koordinaten der Bounding Box, die Klasse und den Konfidenzwert des erkannten Objekts. Die Konfidenz gibt an, zu wie viel Prozent sich das Modell bei dem erkannten Objekt sicher ist. \cite{InferenzResults} 

Diese Informationen können nun direkt für weitere Aktionen verwendet werden. Die detektierte Bounding Box wird dem Frame des Kamera-Streams hinzugefügt und auf dem Bildschirm angezeigt.

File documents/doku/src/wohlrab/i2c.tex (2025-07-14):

\section{I²C}

\subsection{Verkablung über Breadboard (Wohlrab)}

Zur ersten Funktionsüberprüfung des Sensors wurde eine einfache Testschaltung auf einem Breadboard aufgebaut. 
Dabei wurde der Raspberry Pi über die GPIO-Pins mit dem Breadboard verbunden. 
Im nächsten Schritt wurden die Anschlüsse des Ultraschallsensors mit den entsprechenden Leitungen auf dem Breadboard verbunden, um eine grundlegende Funktionalität und Signalübertragung sicherzustellen.

\subsection{Einrichten des Raspberry Pi (Wohlrab)}

Um mit den Sensoren über das I²C-Protokoll kommunizieren zu können, muss der Raspberry Pi entsprechend konfiguriert werden. 
Dazu muss zunächst die I²C-Schnittstelle aktiviert werden, was über die Kommandozeile des Raspberry Pi erfolgt. 
Dies kann mithilfe des Konfigurationswerkzeugs „raspi-config“ durchgeführt werden. 
Dort muss unter dem Punkt „Interfacing Options“ die Option „I2C“ aktiviert werden.

\subsection{Testing der I²C Verbindung (Wohlrab)}

Zur Verifizierung der I²C-Kommunikation zwischen Mikrocontroller und Sensor wurde ein einfaches Python-Skript entwickelt. 
Das Skript initialisiert zunächst die I²C-Schnittstelle und überprüft die Erreichbarkeit des Sensors, indem es die I²C-Adressen ausliest.
Anschließend wird ein einfacher Steuerbefehl an den Sensor gesendet und die Antwort des Sensors ausgewertet. 
Durch diese bidirektionale Kommunikation kann sichergestellt werden, dass sowohl das Senden von Befehlen als auch das Empfangen von Daten über die I²C-Verbindung zuverlässig funktioniert.

\subsection{Ansteuerung der Sensoren über die Software (Wohlrab)}

Um mit einem Sensor über die I²C-Schnittstelle zu kommunizieren, muss zunächst dessen spezifische I²C-Adresse bekannt sein. 
Diese ist in der Regel im Datenblatt des Sensors dokumentiert. 
Alternativ kann die Adresse mit dem Kommandozeilen-Tool „i2cdetect” ermittelt werden. 
Dieses listet die am I²C-Bus angeschlossenen Geräte und deren Adressen aus.
Zur Verbesserung der Lesbarkeit und Flexibilität des Quellcodes werden die I²C-Adressen der Sensoren mittels Define-Anweisungen im Code festgelegt. 
Dies ermöglicht eine einfache Anpassung bei Änderungen der Sensoradressen.
Die Kommunikation beginnt mit dem Öffnen des entsprechenden I²C-Kanals und dem Aufbau einer Verbindung zum Sensor über dessen Adresse. 
Der Datenaustausch erfolgt dabei in einem standardisierten Ablauf: 
Zunächst wird das Zielregister des Sensors adressiert und anschließend werden Befehle oder Daten übertragen. 
Nach Abschluss der Kommunikation wird der I²C-Kanal ordnungsgemäß geschlossen, um die Verbindung zu beenden und Ressourcen freizugeben.

\subsection{Finale Verkabelung (Wohlrab)}

Die endgültige Umsetzung der I²C-Bus-Verkabelung erfolgte mithilfe von Dupont-Crimp-Verbindungen. 
Diese gewährleisten eine individuelle und dennoch zuverlässige Verbindung der Komponenten. 
Wie in Abbildung~\ref{fig:i2c_stecker} dargestellt, wurden auf der Seite des Raspberry Pi sämtliche Leitungen in einem gemeinsamen Stecker zusammengeführt.
Eine Besonderheit dieser Umsetzung ergibt sich aus den unterschiedlichen Spannungsanforderungen der verwendeten Sensoren: 
Da der Gyroskop-Sensor und der Ultraschallsensor unterschiedliche Versorgungsspannungen benötigen, wurde der Stecker so ausgelegt, dass zwei separate Plusleitungen integriert sind. 
Dadurch kann die Spannungsversorgung der Sensoren individuell gestaltet werden.
Die restlichen Leitungen, insbesondere die Daten- und Taktleitungen des I²C-Busses (SDA und SCL), wurden zusammengeführt und in den gemeinsamen Anschluss integriert. 
Auf der Seite der Sensoren verzweigt sich der Bus in zwei separate Stecker, die jeweils mit den entsprechenden Sensoren verbunden sind. 
Diese Struktur ermöglicht eine übersichtliche und modulare Verbindung der Sensoren bei gleichzeitiger Wahrung der elektrischen Anforderungen.
\begin{figure}[ht]
    \centering
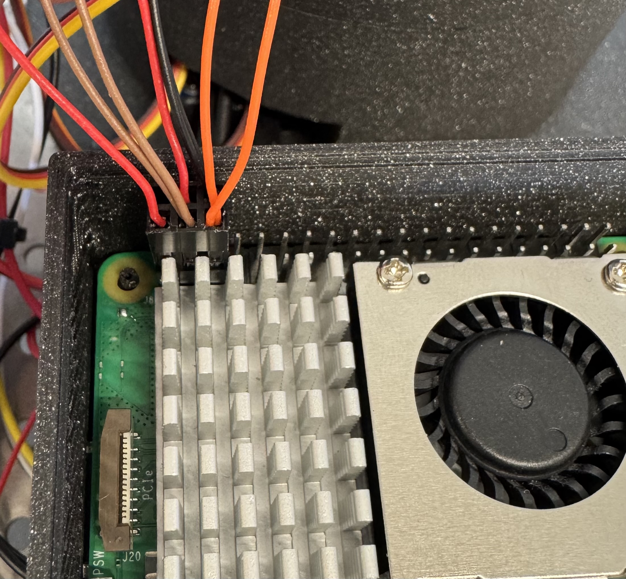
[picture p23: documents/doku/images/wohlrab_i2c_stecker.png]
    
    \caption{Dupont-Crimp-Stecker der finalen I²C-Verkabelung}
    \label{fig:i2c_stecker}
\end{figure}

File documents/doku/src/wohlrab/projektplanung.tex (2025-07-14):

\chapter{Projektplanung}

\section{Definiton (Wohlrab)}

Die anfänglichen Überlegungen zum Projekt beschäftigten sich mit dem grundlegenden Aufbau des Systems.
Dazu wurden zunächst alle Funktionen und die dafür benötigten Komponenten zusammengestellt.
Anschließend wurde überlegt, wie sich die verschiedenen Komponenten miteinander verbinden lassen und welche von welchen Mikrocontrollern gesteuert werden sollen.
Dabei hat sich eine Zweiteilung des Systems ergeben: 
\begin{itemize}
    \item Alle Motoren und Servos sollen mit einem ESP32 verbunden werden.
    Dieser sollte außerdem über eine Bluetooth-Verbindung die Steuerbefehle des PlayStation-Controllers entgegennehmen.
    \item Die gesamte Sensorik des Systems soll über einen Raspberry Pi 5 ausgewertet werden.
    Er sammelt und kombiniert die Informationen aus den Sensorwerten und verarbeitet sie mithilfe eines KI-Modells.
    Dabei sollen Ziele über die Kamera erkannt und ihre Position mithilfe der weiteren Sensoren bestimmt werden.
    Auf dieser Grundlage sollen Steuerungsbefehle für den ESP32 berechnet und an diesen weitergegeben werden.
    Das Video der Kamera soll zudem über einen Webserver dargestellt werden.
\end{itemize}

\section{GANTT-Diagram (Wohlrab)}

Zu Beginn wird eine vollständige Auflistung aller für das Projekt relevanten Komponenten erstellt. 
Aus diesen Komponenten werden die entsprechenden Arbeitspakete abgeleitet.
Im nächsten Schritt erfolgt eine fundierte Abschätzung des Umfangs der einzelnen Arbeitspakete. 
Mithilfe dieser Schätzung wird der zeitliche Aufwand für die Bearbeitung jedes Pakets ermittelt.
Zur besseren Übersichtlichkeit werden die zeitlichen Abhängigkeiten zwischen den Arbeitspaketen dargestellt. 
Diese Darstellung ermöglicht es, die Reihenfolge der Aufgaben und ihre Zusammenhänge zu visualisieren. 
Dadurch wird eine effiziente und systematische Arbeitsweise gewährleistet.
Die Arbeitspakete werden anschließend auf die Gruppenmitglieder verteilt, wobei darauf geachtet wird, dass die Gesamtaufwände innerhalb des Teams ausgewogen sind. 
Dies trägt dazu bei, die Arbeitslast gerecht zu verteilen und die Effektivität des Teams zu maximieren.
Zur besseren Differenzierung sind die verschiedenen Arten von Arbeitspaketen im Diagramm farblich gekennzeichnet.

\section{Lastenheft (Wohlrab)}

Das Lastenheft stellt ein zentrales Dokument im Projektmanagement dar, da es die Anforderungen und Ziele des Projekts formell festhält. 
Es dient der präzisen Definition des Projektumfangs und legt den Rahmen fest, innerhalb dessen das Projekt durchgeführt wird. 
Durch die detaillierte Beschreibung der zu erfüllenden Anforderungen und Zielsetzungen gibt das Lastenheft eine klare Orientierung und leitet alle nachfolgenden Tätigkeiten ab. 
Nach Abschluss des Projekts ermöglicht es zudem eine objektive Beurteilung des Projekterfolgs, da es als Grundlage für die Evaluation der erreichten Ergebnisse und der Zielerreichung dient.

\section{Plakat (Wohlrab)}

Das Plakat ist ein zentrales Element der visuellen Kommunikation des Projekts, da es die wesentlichen Inhalte auf ansprechende Weise veranschaulicht. 
Ziel ist es, das Interesse von Personen zu wecken und ihnen eine schnelle, aber umfassende Übersicht über das Projekt zu vermitteln. 
Der Fokus liegt dabei auf den Hauptfunktionen des Projekts. 
Eine vollständige Aufstellung aller Funktionen wird bewusst vermieden, um die Aufmerksamkeit auf die Schlüsselaspekte zu lenken. 
Das Plakat ist somit ein effektives Kommunikationsmittel, das die wichtigsten Informationen auf klare Weise darstellt.

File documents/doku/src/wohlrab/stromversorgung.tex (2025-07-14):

\section{Versorgung des Raspberry Pi über den 5V Stromkreis (Wohlrab)}

Während der Entwicklung wurde der Raspberry Pi stets separat von der Plattform betrieben und über das Raspberry Pi Netzteil mit Strom versorgt.
Da sich das System frei bewegen können soll, ist es notwendig, dass der Raspberry Pi auch über eine portable Stromquelle betrieben werden kann.
Der einfachste Ansatz ist, den Raspberry Pi an den 5V Verteiler anzuschließen, der bereits auf dem System installiert ist.
Dazu können die entsprechenden GPIO-Pins des Raspberry Pi mit den Ports des Verteilers verbunden werden. 
Hierbei ist darauf zu achten, dass ausreichend dicke Kabel verwendet werden, da der Raspberry Pi bei hoher Auslastung einiges an Strom benötigt. 
Zudem ist der Raspberry Pi ziemlich empfindlich, was die Stabilität des Stroms betrifft. 
Um die Stabilität zu erhöhen, wurden beide 5V Pins und zwei der GND Pins des Raspberry Pi mit dem Stromverteiler verbunden.
Beim Testen hat diese Lösung zunächst auch zuverlässig funktioniert. 
Während der Tests wurden jedoch keine Applikationen auf dem Raspberry Pi ausgeführt und der Roboter wurde nur in einfacher Fahrt bewegt. 
Während der weiteren Entwicklung ist der Raspberry Pi jedoch hin und wieder abgestürzt, wenn auf ihm die Auswertung der Kameradaten lief und parallel die Funktionsfähigkeit des Roboters ausgiebig getestet wurde.
Dabei hat sich herausgestellt, dass der erhöhte Stromverbrauch des Raspberry Pi beim Ausführen unserer Applikationen nicht stabil gewährleistet werden kann, wenn alle anderen Funktionen des Roboters ebenso ausgeführt werden, also Fahren, Bewegen des Geschützes und Schießen gleichzeitig. 
In diesem Volllast-Test konnte die benötigte Spannung nicht aufrechterhalten werden.
Um eine wirklich stabile Stromversorgung für den Raspberry Pi gewährleisten zu können, wird der Raspberry Pi nun mit einer separaten Powerbank versorgt. 
Diese wird im unteren Teil des Roboters im selben Fach mitgeführt in dem auch schon der andere Akku Platz findet und über ein Standard-USB-Kabel mit dem Raspberry Pi verbunden.

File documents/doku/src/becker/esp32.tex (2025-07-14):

\chapter{ESP32 Programmierung}

\section{Einführung (Becker, Specht)}

Die Programmierung der zeitkritischen Funktionalitäten erfolgt unter Verwendung eines \mbox{ESP-32}, da bestimmte Funktionen strengere zeitliche Anforderungen aufweisen, als dies mit einem General-Purpose-Betriebssystem realisierbar wäre.

Nach Abwägung aller relevanten Faktoren wurde sich dazu entschieden, den klassischen \mbox{ESP-32} Chip zu wählen, da dieser den Bluetooth Classic Standard unterstützt. 
Dieses Protokoll wird für die Ansteuerung des Dualshock4-Controllers benötigt.
Darüber hinaus trägt das weite Verbreitungsgebiet dieser Serie dazu bei, dass eine Vielzahl an Material zur Verfügung steht, was wiederum die Fehlersuche erheblich vereinfacht.

Es wurde jedoch ausdrücklich darauf verzichtet, den Controller unter Verwendung des Arduino Frameworks zu programmieren. 
Die Ursache hierfür war insbesondere die Größe der entstehenden Kompilate. 
Es sei darauf hingewiesen, dass das System über zahlreiche Funktionalitäten verfügt, was eine begrenzte Speicherverfügbarkeit zur Folge hat. 
Daher erfolgte die Programmierung des Controllers unter Verwendung des \textit{Espressif IoT Development Frameworks} (ESP-IDF) \cite{esp_esp_idf}. 
Dieses Framework stellt ebenfalls eine Vielzahl von Treibern für unterschiedliche Funktionen bereit, ist jedoch gezielt für Espressif-Controller konzipiert und zeichnet sich dadurch aus, dass es einen geringen Speicherplatzbedarf aufweist. 

Die Programmierung erfolgte in der Programmiersprache C und nutzt das Betriebssystem FreeRTOS, welches von Espressif auf Multiprozessoren portiert wurde.

\section{Dualshock4 Treiber (Becker)}

Gemäß der Anforderung ist die Steuerung des Fahrzeugs, sowie der Geschützplattform durch einen DualShock4-Controller vorgesehen. 
Einerseits dient dies dem Testen der Plattformsteuerung für den späteren Betrieb der KI, zusätzlich fungiert sie auch als Gamification-Element. 
Das Ziel ist die Steigerung des Nutzens und der Freude an dem Projekt, indem eine bekannte Steuerungsmethode verwendet wird, welche die Benutzerfreundlichkeit erhöht.

Für die Realisierung dieser Funktionalität wurde ein spezieller Treiber entwickelt, der den Zustand des Controllers in regelmäßigen Abständen an den ESP-32 übermittelt. 
Darüber hinaus umfasste mein Wunsch die Implementierung von Funktionen, die Vibrationen und Farbwechsel am Gamepad auslösen können und zwar vom Mikrocontroller aus.

\subsection{Übertragung}

Vor jeglicher Datenübertragung muss zunächst eine Kopplung per Bluetooth hergestellt werden. 
Der Sony Dualshock 4 Controller verwendet in diesem Fall den Bluetooth Classic 4.0 Standard.
Für die Verbindung des Controllers mit den Geräten ist im Flash-Speicher des Gamepads eine MAC-Adresse gespeichert. 
Beim Anschalten des Controllers wird versucht, Kontakt zu dieser Adresse aufzubauen.
Unter normalen Betriebsbedingungen wäre dies die Adresse der PlayStation4 Konsole. 
Für unser Projekt wurde jedoch die gespeicherte MAC-Adresse mit der des ESP-32 überschrieben.
Nach dem Einschalten unternimmt das Gamepad dann sofort den Versuch, sich mit dem Mikrocontroller zu verbinden.
Das zum Überschreiben der MAC-Adresse verwendete Programm ist im Order \texttt{esp/ds4-mac-change} zu finden.

Die Übertragung der Daten zwischen Gamepad und Mikrocontroller erfolgt mittels sogenannter HID-Reports.
HID-Reports sind binäre Datenstrukturen, welche die Reihenfolge der Informationen festlegen.
Die Struktur der Reports wurde von Sony nicht öffentlich zur Verfügung gestellt, allerdings war es einigen Personen möglich, durch Reverse-Engineering wichtige Felder zu ermitteln \cite{esp_ds4_hid_reports}.

Das Human Interface Device (HID)-Protokoll ist ein standardisiertes Kommunikationsprotokoll zur Übertragung von Eingabe- und Steuerdaten zwischen Peripheriegeräten (z.B. Tastaturen, Mäusen, Gamepads) und einem Host-System. 
Es wurde ursprünglich für USB spezifiziert \cite{esp_usb_hid_spec} und später für Bluetooth Classic übernommen.

\begin{figure}[ht]
    \centering
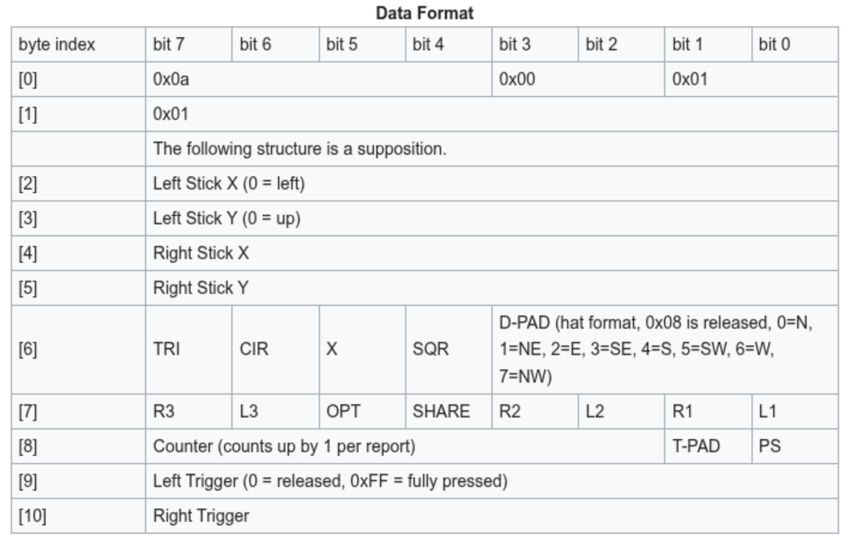
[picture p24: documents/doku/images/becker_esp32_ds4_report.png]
    
    \caption{Beispielhafter Aufbau eines HID-Reports aus \cite{esp_ds4_hid_reports}}
\end{figure}

\subsection{Version 1: eigens entwickelter Treiber}

Eine Websuche nach existierenden DualShock-4 Treibern für das ESP-IDF brachte zunächst nur veraltete Implementierungen zutage, die auf nicht mehr unterstützten APIs basierten. 
Zahlreiche andere Ansätze zielten ausschließlich auf das Arduino-Framework ab und ließen sich daher nur eingeschränkt oder gar nicht in ein ESP-IDF basiertes Projekt integrieren.

Da die Struktur der vom Gamepad gesendeten HID-Reports dank Reverse Engineering bekannt war und das ESP-IDF über eine Bluetooth-HID-Host-API verfügte \cite{esp_hib_bt_api}, wurde im ersten Ansatz ein eigener Treiber entwickelt.

Der Verbindungsaufbau verlief problemlos, und zu Beginn wurden die Input-Reports korrekt empfangen. 
Nach kurzer Zeit fror die Datenübertragung jedoch ein, obwohl alle anderen Tasks auf dem System weiterhin fehlerfrei ausgeführt wurden. 
Recherchen ergaben, dass dieses Verhalten auch von anderen Nutzern beobachtet wurde \cite{esp_hib_bt_api_issues}. 
Als Ursache wird die vergleichsweise hohe Sendefrequenz des Controllers vermutet, die laut Nutzertests bei über 700 Hz liegt \cite{esp_ds4_hid_reports}.

Um den Overhead in der Callback-Funktion für empfangene Reports zu reduzieren, wurde ein Zeitfilter implementiert. 
Ein Timer prüft beim Eintreffen eines Reports, ob seit dem letzten verarbeiteten Report mindestens $16.\overline{6}$ ms (entsprechend 60 Hz) vergangen sind. 
Ist dies der Fall, wird der aktuelle Report in eine durch FreeRTOS bereitgestellte Queue eingereiht. 
Diese wird von einem separaten Task abgearbeitet, der die Reports auf der Konsole protokolliert. 
Auf diese Weise konnte das Logging, das potenziell blockierend wirkt, vom zeitkritischen Pfad entkoppelt werden.

Obwohl diese Maßnahme die Zeitspanne, in der die Daten stabil übertragen wurden, verlängerte, wurde das zugrundeliegende Problem damit nicht vollständig gelöst. 
Nach einigen Minuten brach der Controller die Übertragung der Reports erneut ab, obwohl die Status-LED weiterhin eine aktive Bluetooth-Verbindung anzeigte.

Da der ESP-32 in dieser Anwendung zusätzlich weitere zeitkritische Komponenten wie den Motortreiber verwalten muss, ist die Stabilität und Effizienz des Treibers von zentraler Bedeutung.
Aus diesem Grund wurde entschieden, die Entwicklung eines eigenen Treibers nicht weiter zu verfolgen und stattdessen nach einer robusteren und getesteten Alternative zu suchen.

\subsection{Version 2: Treiber basierend auf der Bluepad32 Bibliothek}

Als Alternative wurde die Bibliothek Bluepad32 evaluiert. Diese ermöglicht das Auslesen von Gamepad-Daten auf verschiedenen Mikrocontrollern, darunter auch dem ESP32.

Ein wesentlicher Vorteil dieser Bibliothek liegt darin, dass bereits eine Vielzahl von Controllern unterstützt wird. 
Darüber hinaus erlaubt sie auch die Steuerung von Zusatzfunktionen wie der Vibrationsmotoren und der LED-Farbleiste des Gamepads. 
Im Gegensatz zum im ESP-IDF integrierten Bluedroid Bluetooth-Stack verwendet Bluepad32 den sogenannten BTStack.
Dieser wurde ursprünglich für 8- und 16-Bit-Mikrocontroller entwickelt und ist dadurch deutlich ressourcenschonender. \cite{BTStack}

Ein entscheidender Nachteil ist jedoch die vergleichsweise geringe Dokumentation zur Integration in das IoT Development Framework (ESP-IDF). 
Im Gegensatz zum Arduino-Framework ist die Unterstützung hier deutlich schwächer ausgeprägt, daher wurde Bluepad32 im vorherigen Schritt zunächst verworfen. 
Die Möglichkeit, im Code-Editor direkt zu den verwendeten Funktionsdefinitionen springen zu können, erwies sich in diesem Fall als sehr hilfreich. \cite{bluepad32}

Letztlich konnte ein funktionsfähiger Treiber implementiert werden, der neben dem Auslesen der Controllereingaben auch die Steuerung der Vibration und Farbwechsel unterstützt.
Der schematische Aufbau des Treibers ist in Abbildung~\ref{fig:ds4_driver} dargestellt:

\begin{figure}[ht]
    \centering
    
    \caption{Aufbau des Dualshock4 Treibers}
    \label{fig:ds4_driver}
\end{figure}

\begin{itemize}
    \item Der \textbf{bluepad32\_task} führt sowohl den BTStack als auch die Bluepad32 Bibliothek aus. 
    Über die dort eingebundene Plattform (eine Menge von Callback-Funktionen) erfolgt die Kommunikation mit dem Gamepad. 
    Beispielsweise wird beim Eintreffen eines Controller-Datenpakets (Callback \textit{on\_controller\_data}) die \textbf{ds4\_input\_queue} mit aktuellen Informationen zu Tasten, Sticks und Batteriestand gefüllt.
    Dies erfolgt mit einer Frequenz von 60 Hz. 
    Zusätzlich wird überprüft, ob der Batteriestand unter eine kritische Grenze fällt, in diesem Fall wird das Event-Bit \textit{DS4\_BATTERY\_LOW} gesetzt bzw. wieder entfernt. 
    Die Callbacks \textit{on\_device\_ready} und \textit{on\_device\_disconnected} aktualisieren den Verbindungsstatus, welcher im Event-Bit \textit{DS4\_CONNECTED} gespeichert ist.
     
    \item Die \textbf{ds4\_input\_queue} ist eine von FreeRTOS bereitgestellte Queue, die thread- bzw. multiprozessorsicher ist.
    Hier kann der aktuelle Zustand des Controllers am Treiberinterface abgegriffen werden.

    \item Der Verbindungsstatus kann über die Funktionen \textbf{ds4\_is\_connected()} (nicht blockierend), sowie \textbf{ds4\_wait\_for\_connection()} (blockierend) abgefragt werden. 
    Letztere blockiert den aufrufenden Task, bis eine Verbindung besteht. 
    Diese Funktion wird z.B. von der Regelschleife der Fahrzeugsteuerung verwendet (vgl. Kapitel~\ref{sec:esp32_integration}) und basiert auf den FreeRTOS EventGroups.

    \item Farbänderungen und Vibrationsbefehle können in Bluepad32 ausschließlich aus dem Haupttask (\textbf{bluepad32\_task}) heraus gesendet werden. 
    Um auch außerhalb der Plattform-Callbacks Effekte steuern zu können, werden entsprechende Befehle über die Funktion \textbf{ds4\_rumble()} bzw. \textbf{ds4\_lightbar\_color()} in die \textbf{ds4\_output\_event\_queue} eingetragen.
    Diese Vorgehensweise sorgt dafür, dass die Funktion auch gleichzeitig von beiden Prozessor-Kernen aufgerufen werden kann.
    Die Verarbeitung der Queue erfolgt dann sequenziell durch den \textbf{ds4\_output\_event\_task}, der die Events beim \textbf{bluepad32\_task} registriert.

    \item Schließlich kann ein niedriger Batteriestand durch ein rotes Blinken der Lichtleiste am Gamepad signalisiert werden. Dazu wird der \textbf{ds4\_low\_battery\_signal\_task} aktiviert, sobald das Event-Bit \textit{DS4\_BATTERY\_LOW} gesetzt ist. 
    Währenddessen werden andere Farbbefehle verworfen.
\end{itemize}

\subsection{Testing}

Zum Testen des implementierten Treibers wurden zwei separate Tasks auf dem ESP32 erstellt:

\begin{itemize}
    \item \textbf{Input-Test Task}: Dieser Task wartet zu Beginn jeder Schleife blockierend auf eine bestehende Verbindung mit dem DualShock-Controller. 
    Sobald die Verbindung hergestellt ist, blockiert der Task an der Input-Queue, bis ein Zustandsreport vom Controller eintrifft. Der empfangene Report wird aus der Queue entnommen und auf der Konsole ausgegeben. 
    Anschließend erfolgt eine Wartezeit von $16.\overline{6}$\,ms, entsprechend einer Frequenz von 60 Hz.
    
    \item \textbf{Output-Test Task}: Auch dieser Task wartet zunächst auf eine erfolgreiche Verbindung mit dem Gamepad. 
    Nach dem Verbindungsaufbau wird jeweils ein Vibrations- und ein Farbwechselevent in die Output-Queue eingetragen. 
    Da dem Vibrationsbefehl eine Dauer von 100 ms zugewiesen wurde, pausiert der Task entsprechend lange.
\end{itemize}
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

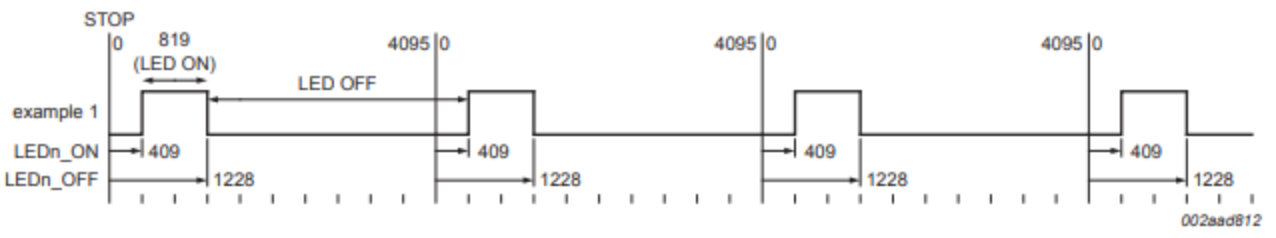
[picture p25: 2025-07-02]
documents/doku/images/becker_esp_pca9685.png

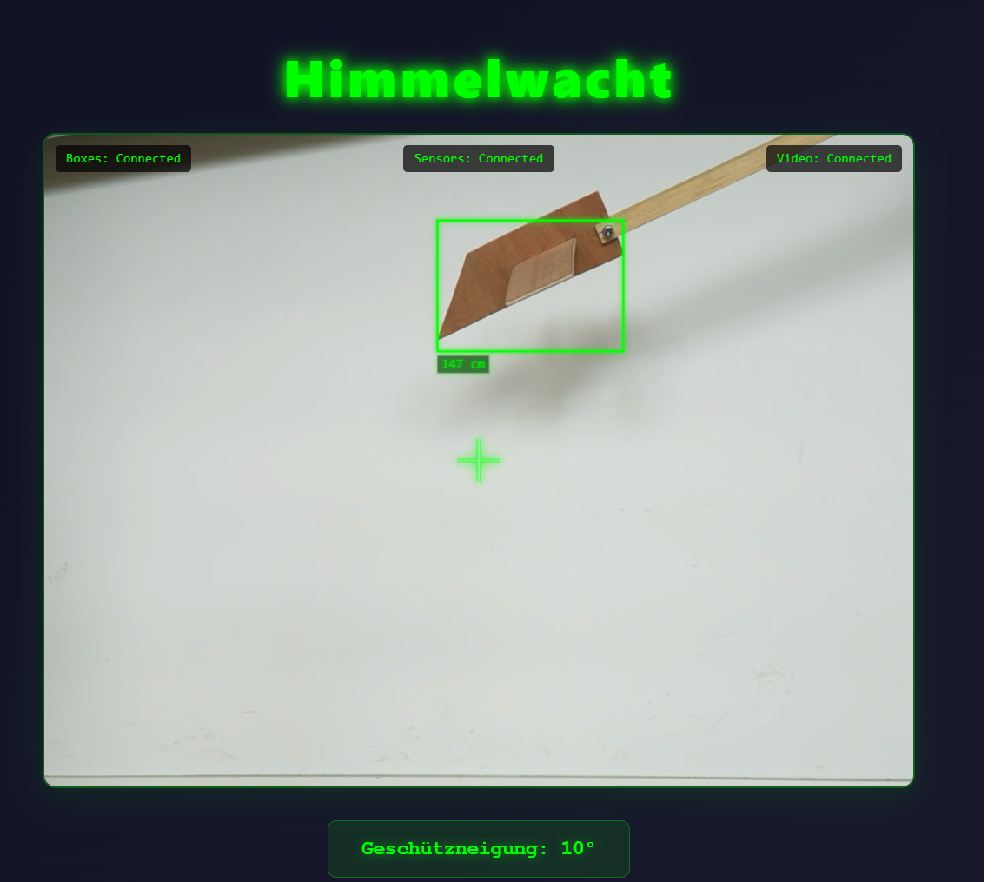
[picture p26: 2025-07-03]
documents/doku/images/Webserver.png

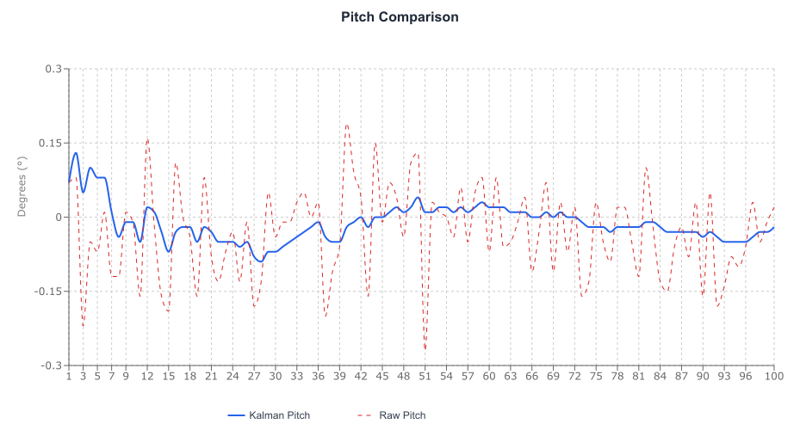
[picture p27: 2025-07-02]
documents/doku/images/kalman_comparison_pitch_2025-06-23.png

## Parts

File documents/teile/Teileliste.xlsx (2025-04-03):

Teileliste
Bauteil | Anzahl | Vorhanden | Bestellen | Drucken | Details
Raspi 5 | 1 | X
ESP 32 | 1 |  | X |  | https://www.az-delivery.de/en/products/nodemcu-esp-32s-kit?variant=39436421496928
Bluetooth-Antenne | 1 |  | X |  | https://www.amazon.de/MakerMind-Antenne-Bluetooth-Boards-ESP32-CAM/dp/B0DBZNYDWZ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
Kühler Raspi | 1 |  | X |  | https://www.amazon.de/dp/B0CLXZBR5P
Kamera | 1 | X
Lautsprecher | 1 | X
Fahrgestell | 1 | X
Gyrosensoren | 3 | X
Ultraschall | 1 | X
Fly Wheel | 2 | X
Servo-Motoren | 3 | X
Flieger | 1 | X
Controler | 1 | X
Akku | 1 | X
(Stromversorgung für Raspi) | 1 |  | (X) |  | (Akku Shield für Raspi)
Steckverbindungen
Pro Mini | 3 | X
Plattform | 1 |  |  | X
Geschütz | 1 |  |  | X
Netzteil für Raspi (Programmierung) | 1 | X
Nervdarts | 20 |  | X |  | https://www.amazon.de/Nerf-Elite-20er-Dart-Nachfüllpackung/dp/B087YHTB2Z?__mk_de_DE=ÅMÅŽÕÑ&s=toys
ULN2003 Driver Board | 2 |  | X |  | https://www.amazon.de/ICQUANZX-stücke-ULN2003-Schrittmotor-Treiberplatine/dp/B07VQ856M9?__mk_de_DE=ÅMÅŽÕÑ

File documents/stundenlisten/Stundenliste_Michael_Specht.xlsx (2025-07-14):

Stundenliste
Name: |  | Michael Specht
Gruppe: |  | 1 Himmelwacht
Pos. | Bezeichung | Beschreibung | Stunden in h
1 | Einführung | Gruppe, Thema, Herangehensweise | 4
2 | Einführung | GANTT, Lastenheft, Einteilung, Teileliste | 8
3 | Flieger | Fliegermodell inkl. Befestigungsarm bauen | 2
4 | CAD | Einführung in 3D-Druck, Software, Aufteilung | 5
5 | CAD | Geschützarm v1 | 15
6 | Recherche | Motor-Control-PWM (MCPWM), Motor + Treiber | 5
7 | HW Setup | Widerstände + Kondensatoren löten | 2
8 | ESP-IDF | Programmierung Motortreiber | 15
9 | ESP-IDF | Programmierung Differential Drive | 10
10 | Test | Test am Fahrzeug + Debugging (Motortreiber) | 5
11 | Test | Test am Fahrzeug + Debugging (Differential Drive) | 10
12 | Integration | Differential Drive, Steuerung mittels Controller | 5
13 | Integrationstest | Deadzones + Algorithmus anpassen | 10
14 | HW Setup | Debugging, Widerstände entfernen, neuer Akku | 2
15 | CAD | Geschützarm v2 | 10
16 | CAD | Pololu Halterung | 1
17 | HW Setup | Diverse Arbeiten für Zusammenbau | 3
18 | HW Setup | Riemen-Trieb zerlegt, gereinigt, zusammengebaut | 2
19 | Test | Leistung neue Flywheelmotoren | 2
20 | ESP-IDF | Logik-Umbau auf Festkommaarithmetik | 3
21 | ESP-IDF | Integration WiFi- + MQTT-Stack | 15
22 | Integration | Test am Fahrzeug + Debugging (MQTT) | 5
23 | 3D-Druck | Diverse Drucks begleitet (Slicer, Infill entfernen) | 5
24 | Präsentation | PowerPoint anpassen | 3
25 | Objekttracking | Implementierung + Testen des Objekttrackings | 6
26 | Dokumentation | Wissenschaftliche Arbeit verfassen | 20
 |  | Gesamt: | 173

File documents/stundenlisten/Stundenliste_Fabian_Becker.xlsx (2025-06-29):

Stundenliste
Name: |  | Fabian Becker
Gruppe: |  | 1 HimmelWacht
Pos. | Bezeichung | Beschreibung | Stunden in h
1 | Vorbereitung | Gruppenbildung, Projektfindung, erste Recherche | 4
2 | Projektorganisation | Erstellung Projektbeschreibung, Terminplan & Plakat | 8
3 | CAD Design | Einarbeitung FreeCAD | 5
4 | CAD Design | Entwurf Platform, Anpassung Magazin & Schussarm | 11
5 | Ps4 Controller Treiber | Einarbeitung ESP-IDF, erster Entwurf mit Bluetooth HID | 3
6 | Ps4 Controller Treiber | Debugging PS4 Treiber aufgrund ESP Freeze | 10
7 | Ps4 Controller Treiber | Erstellung ESP32 Projekt mit Bluepad32 Dependencies | 2
8 | Ps4 Controller Treiber | Erstellung Custom Bluepad32 Plattform | 4
9 | Ps4 Controller Treiber | Implementierung Datenabgriff, Vibration, Farbwechsel | 8
10 | Ps4 Controller Treiber | Treiber auf Multiprozessor portiert | 6
11 | Ps4 Controller Treiber | Low Battery Warning durch rote blinkende LED | 3
12 | CAD Design | Design + Druck für Stromversorgung und Motortreiber | 6
13 | PWM Treiber | Portierung PCA9685 für Servosterung | 4
14 | Plattformsteuerung | Gradweise Ansteurung für Servomotoren implementiert | 6
15 | CAD Design | Redesign + Druck Schussarm und Magazin | 5
16 | Lautsprecher | Treiberboard gelötet und Test Lautsprecher | 5
17 | Flywheel Motoren | Test Flywheelmotoren + Implementierung Treibercode | 5
18 | Geschütz | Zusammenbau, Kalibrierung Servos | 10
19 | Geschütz | Integration PS4 Treiber | 15
20 | CAD Design | Druck & Design Mikrocontroller Cases | 10
21 | Stromversorgung | Finale Verkabelung ESP32 | 6
22 | Gesamttests | Integriertes Fahrzeug getestet (Controller & Platform) | 4
23 | Plattformsteuerung | Implementierung Moduswechsel (manuel <-> KI) | 2
24 | Ps4 Controller Treiber | Tiefpassfilter zur Unterdrückung von Jitter implementiert | 3
25 | Abschlusspräsentation | Präsentationsfolien erstellt & Bilder aufgenommen | 3
26 | Objekttracking | Implementierung & Testen des Objekttrackings | 3
27 | Dokumentation | Erstellung der wissenschaftlichen Dokumentation | 20
 |  | Gesamt: | 171

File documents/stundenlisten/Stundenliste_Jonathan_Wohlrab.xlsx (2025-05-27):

Stundenliste
Name: |  | Jonathan Wohlrab
Gruppe: |  | HimmelWacht
Pos. | Bezeichung | Beschreibung | Stunden in h
1 | Projektdefinition | Initiale Gedanken zum Projekt | 3
2 | Projektplanung | Erstellung GANTT-Diagramm, Lastenheft und Plakat | 6
3 | Projektvorbereitung | Einrichtung DIE und Erstellung Teileliste | 2
4 | KI Modell | Labeln von Trainingsdaten | 1
5 | I2C Anbindung | Erstellung Verkabelung, Code und Test für I2C-Verbindung | 5
6 | Einrichtung Gyro | Einlesen Datenblätter und Verbindungsaufbau | 3
7 | Zielberechnung | Konzeptionelle Planung zur Ziel-Vorausberechnung | 1
8 | Gyro-Sensor Werte | Auslesen und Verarbeitung der Gyro-Sensor Werte | 10
9 | Lautsprecher | Verkabelung und Testing des Stereo-Modus | 2
10 | FlyWheels | Verkabelung und Testing | 5
11 | Ultraschallsensor | Verkabelung und Auslesen der Messwerte | 5
12 | Dokumentation | Schreiben LaTeX Template und Erstellung Stundenliste | 6
13 | Testing | Testing des Manuellen Modus | 1
14
15
16
17
18
19
20
21
22
23
24
25
26
27
28
29
30
31
32
33
34
35
36
37
38
39
40
41
42
43
 |  | Gesamt: | 50

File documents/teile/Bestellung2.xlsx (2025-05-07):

Bestellung 2
Teil | Begründung | Link
I2C Amplifier Boards (3 Stück) | Stereo Sound über 2 Lautprecher mit Rapsi -> 2 Boards, Lautsprecher da | https://www.amazon.de/Hailege-MAX98357-Amplifier-Breakout-Filterless/dp/B0CJY1C287/ref=sr_1_3?sr=8-3
Kondensator Pololu | Keine mehr im Labor (diese Größe) | https://www.amazon.de/St%C3%BCck-Elektrolytkondensatoren-THT-1000%C2%B5F-%C3%9810x20mm/dp/B0DQHJ86YB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
Schaltdraht 1,5 mm rot/schwarz |  | https://www.amazon.de/SCHWARZBERG-Fahrzeugleitung-Aderleitung-Litzenkabel-Kupferkabel-rot-schwarz/dp/B09J43GBWF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
Flachbandkabel |  | https://www.amazon.de/QWORK-Flachbandkabel-Breadboard-Stiftleisten-Steckverbinder/dp/B09R42ZGQD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
Din verteiler |  | https://www.amazon.de/Stromverteiler-Verteiler-incl-Montagematerial-belastbar/dp/B0DHQZ88F8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
130 dc motor |  | https://www.amazon.de/DollaTek-10-St%C3%BCcke-DC-Arduino/dp/B07HBWFKWL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

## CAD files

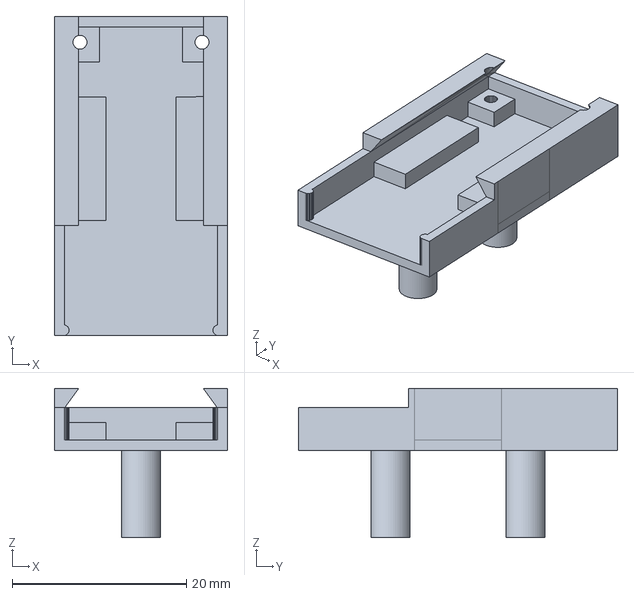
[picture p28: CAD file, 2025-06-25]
cad/FreeCAD/xy-mos-holder.FCStd
19.9 x 36.6 x 17.1 mm

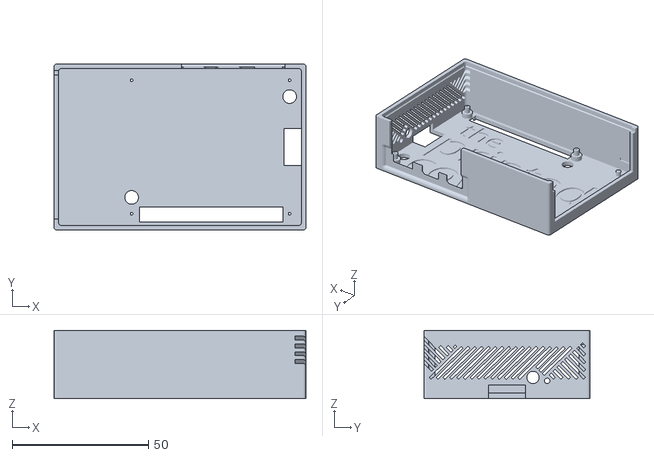
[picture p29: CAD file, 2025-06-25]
cad/imports/import_pi5_case_bottom.stl
92.5 x 61.0 x 25.0

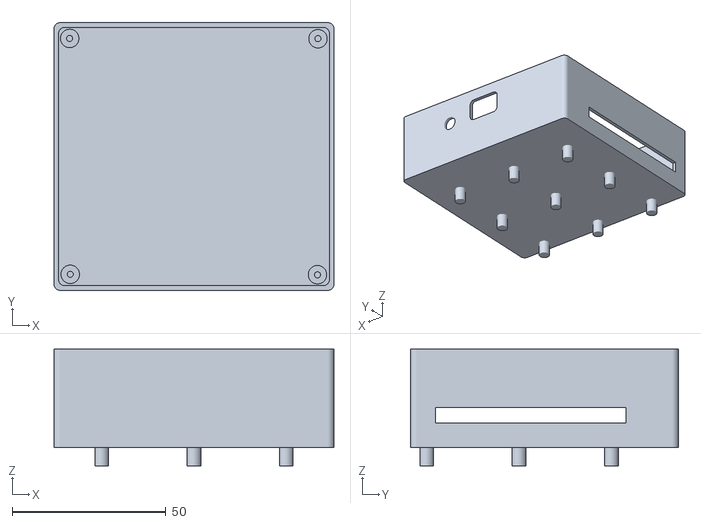
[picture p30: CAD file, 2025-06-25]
cad/output/esp-case-bottom.stl
91.0 x 87.0 x 38.0

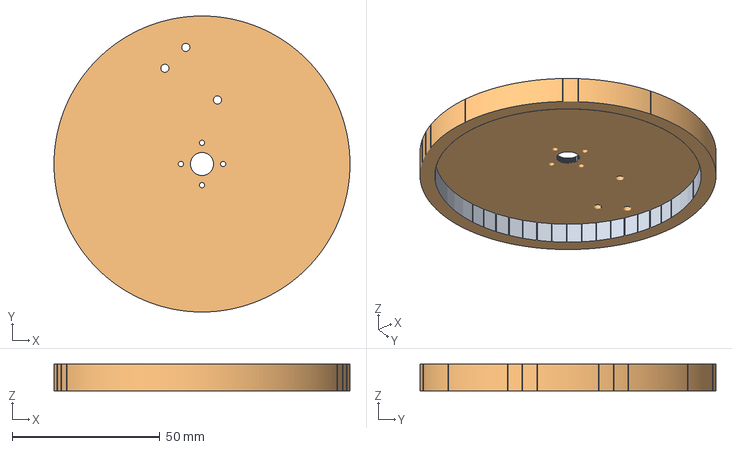
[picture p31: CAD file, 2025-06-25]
cad/FreeCAD/platform.FCStd
100.0 x 100.0 x 9.00 mm
platform-shoulder-screws
platform-shoulder-screws (Meshed)

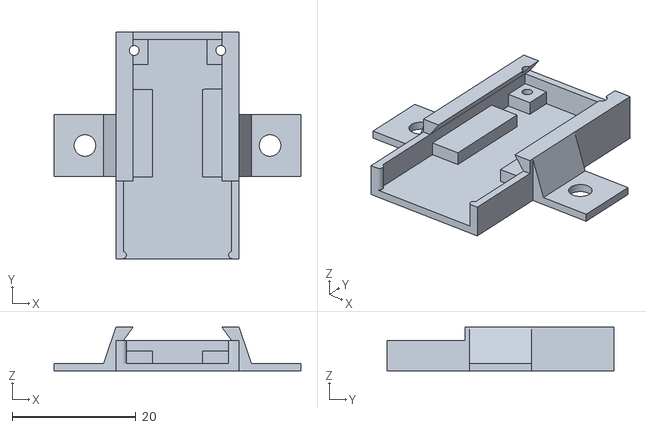
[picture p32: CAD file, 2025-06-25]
cad/imports/import_xy_mos_holder.stl
39.9 x 36.6 x 7.10

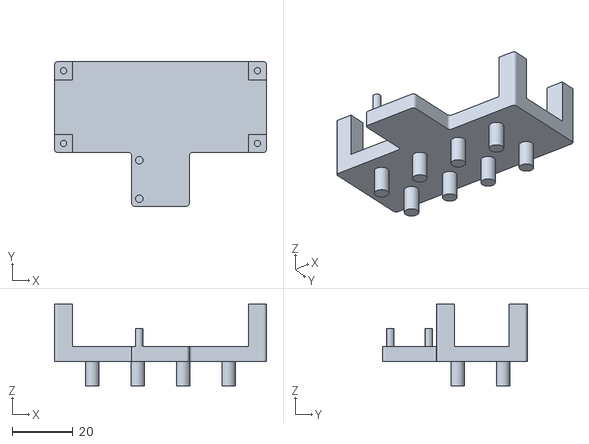
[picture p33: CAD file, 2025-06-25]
cad/output/speaker-plate.stl
70.0 x 47.8 x 27.0

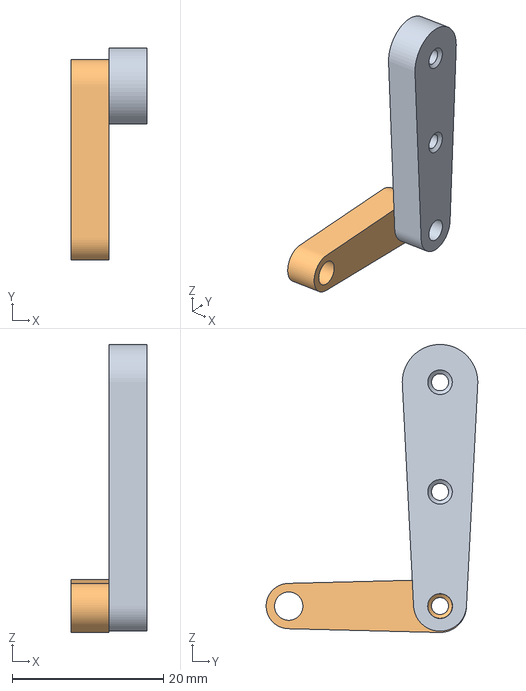
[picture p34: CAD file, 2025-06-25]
cad/FreeCAD/servo-trigger.FCStd
10.0 x 28.0 x 38.1 mm
servo-trigger001
trigger-extension001

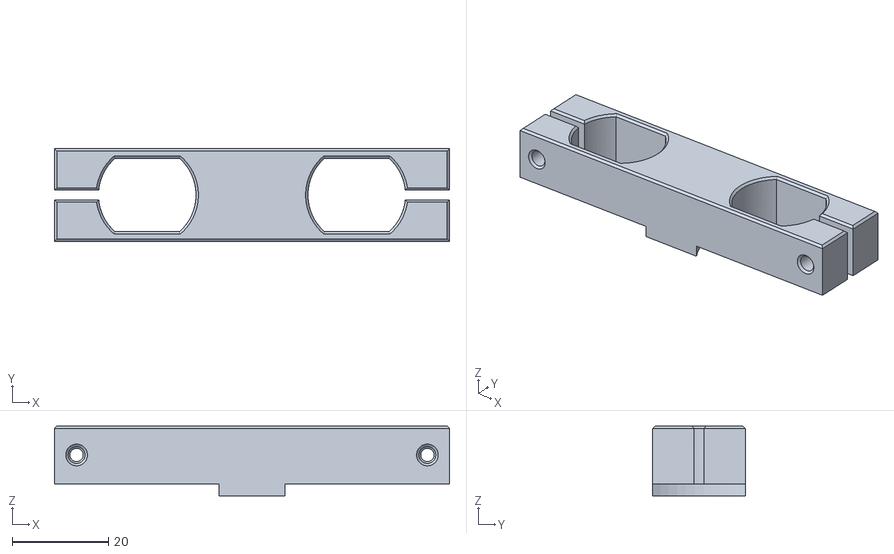
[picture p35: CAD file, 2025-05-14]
cad/imports/import_motor_mount.stl
82.0 x 19.3 x 14.5

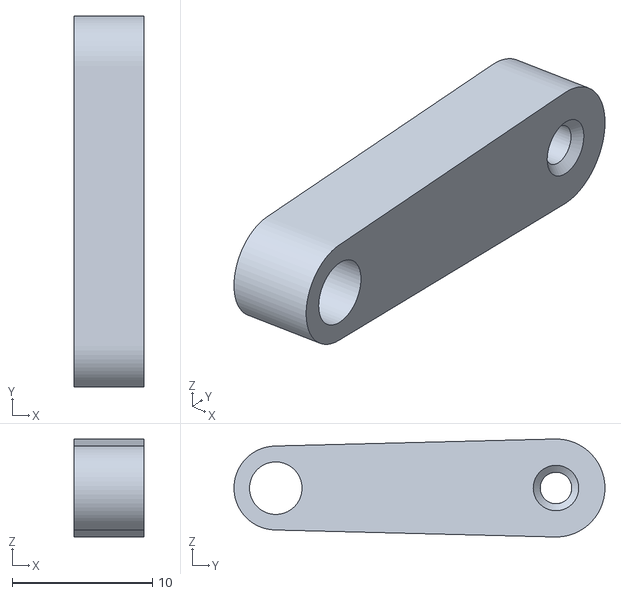
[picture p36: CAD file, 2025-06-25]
cad/output/trigger-extension.stl
5.00 x 26.5 x 7.00

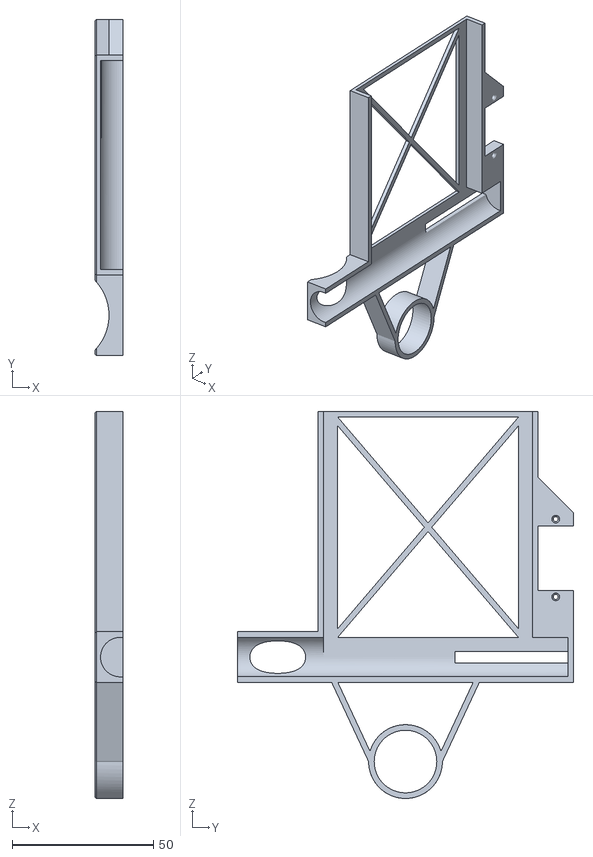
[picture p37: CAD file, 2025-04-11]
cad/imports/import_right_mag.stl
10.0 x 119.0 x 137.1

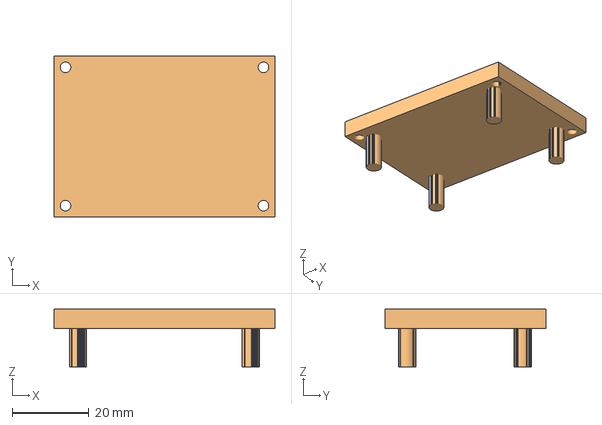
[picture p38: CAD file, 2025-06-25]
cad/FreeCAD/powerplate.FCStd
57.5 x 42.0 x 15.0 mm
Base-final
Base-final (Meshed)

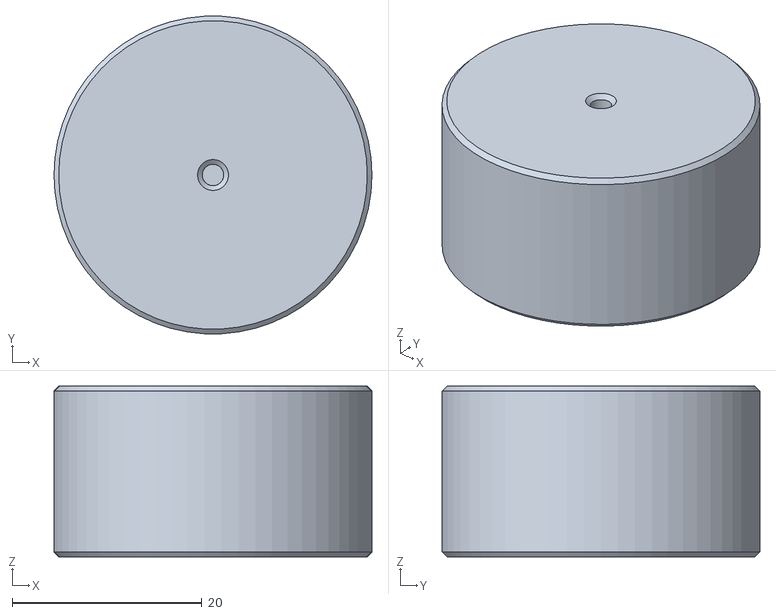
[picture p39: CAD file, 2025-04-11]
cad/imports/import_flywheel.stl
33.5 x 33.5 x 18.0

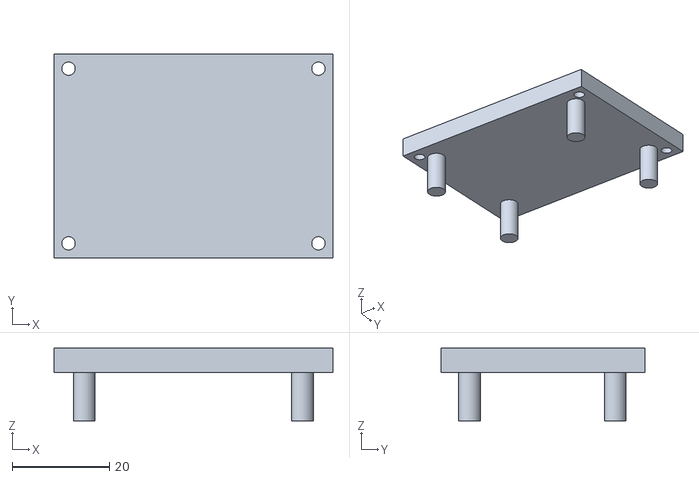
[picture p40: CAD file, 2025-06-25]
cad/output/powerplate-top.stl
57.5 x 42.0 x 15.0

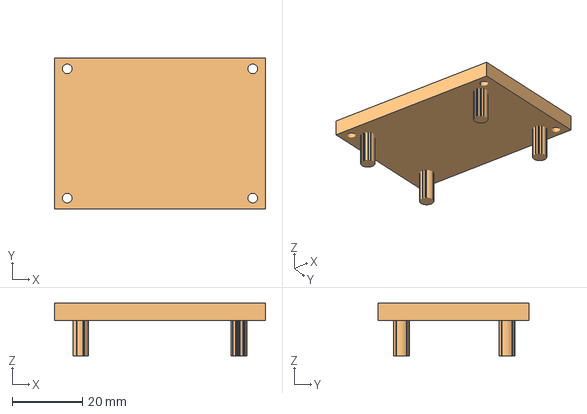
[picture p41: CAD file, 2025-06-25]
cad/FreeCAD/powerplate-top.FCStd
60.0 x 43.0 x 15.0 mm
Base-final
Base-final (Meshed)001

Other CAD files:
cad/FreeCAD/speaker-plate.FCStd
cad/output/xy-mos-holder.stl
cad/imports/import_servo.stl
cad/output/platform.stl
cad/FreeCAD/pololu.FCStd
cad/FreeCAD/shoulder.FCStd
cad/FreeCAD/weight.FCStd
cad/imports/import_gyro_mount.stl
cad/imports/import_left_mag.stl
cad/output/esp-case-top.stl
cad/output/flywheel-final.stl
cad/output/gun-arm.stl
cad/output/left-mag.stl
cad/output/pololu-mount.stl
cad/output/powerplate.stl
cad/output/right-mag.stl
cad/output/servo-trigger.stl
cad/output/shoulder.stl
cad/output/weight.stl

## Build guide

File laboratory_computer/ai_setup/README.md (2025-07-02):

# AI

Contains scripts for creating the directory structure of the dataset, training script with the corresponding data.yml and the script to track the system load while inferencing on the
test video in ../misc.

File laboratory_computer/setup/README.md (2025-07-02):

# Setup
Contains a setup script for the laboratory computer to create execution environment for the webRTC stream, AI inference, MQTT connection and more.

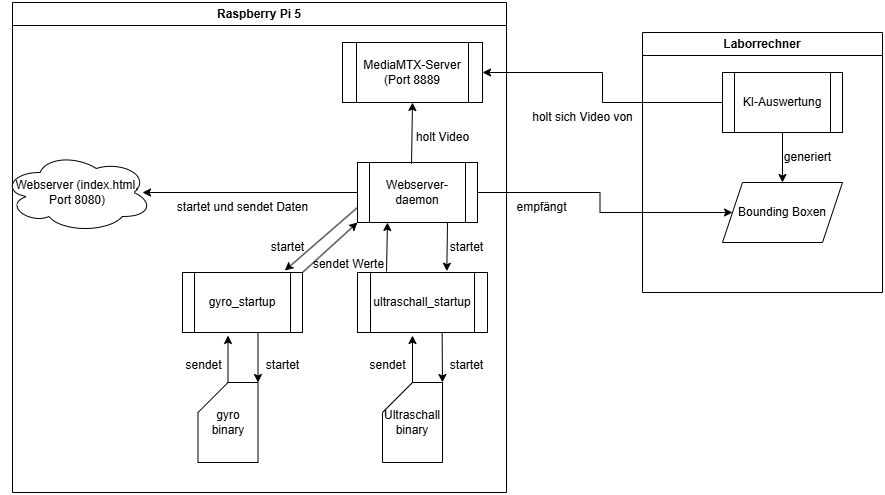
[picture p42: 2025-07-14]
documents/doku/images/Architekturaufbau_webserver.png

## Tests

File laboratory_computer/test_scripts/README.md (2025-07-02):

# test_scripts

Contains simple test scripts to check setup, websocket connection and the engine control via mqtt.

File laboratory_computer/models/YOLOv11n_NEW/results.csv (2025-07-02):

epoch | time | train/box_loss | train/cls_loss | train/dfl_loss | metrics/precision(B) | metrics/recall(B) | metrics/mAP50(B) | metrics/mAP50-95(B) | val/box_loss | val/cls_loss | val/dfl_loss | lr/pg0 | lr/pg1 | lr/pg2
1 | 9.296 | 0.67916 | 2.22065 | 0.93533 | 1 | 0.07807 | 0.32093 | 0.22926 | 0.69749 | 3.0242 | 0.90121 | 0.000653595 | 0.000653595 | 0.000653595
2 | 17.5174 | 0.70005 | 1.36004 | 0.92247 | 0.83003 | 0.73992 | 0.87294 | 0.69999 | 0.74016 | 1.71736 | 0.96387 | 0.00131155 | 0.00131155 | 0.00131155
3 | 25.5299 | 0.70545 | 1.1408 | 0.9198 | 0.89618 | 0.82251 | 0.91588 | 0.70943 | 0.78006 | 1.43689 | 0.95525 | 0.0019607 | 0.0019607 | 0.0019607
4 | 33.4161 | 0.71164 | 0.95598 | 0.9463 | 0.92863 | 0.90127 | 0.95658 | 0.79468 | 0.72661 | 0.87561 | 1.01829 | 0.0019604 | 0.0019604 | 0.0019604
5 | 41.3533 | 0.68294 | 0.84672 | 0.93829 | 0.97739 | 0.93552 | 0.97506 | 0.8017 | 0.66878 | 0.77441 | 0.92632 | 0.0019472 | 0.0019472 | 0.0019472
6 | 49.311 | 0.62212 | 0.71332 | 0.90975 | 0.8984 | 0.78788 | 0.85906 | 0.67475 | 0.84022 | 1.23226 | 0.98174 | 0.001934 | 0.001934 | 0.001934
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

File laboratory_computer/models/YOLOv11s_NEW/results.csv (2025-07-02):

epoch | time | train/box_loss | train/cls_loss | train/dfl_loss | metrics/precision(B) | metrics/recall(B) | metrics/mAP50(B) | metrics/mAP50-95(B) | val/box_loss | val/cls_loss | val/dfl_loss | lr/pg0 | lr/pg1 | lr/pg2
1 | 11.8637 | 0.65484 | 3.12283 | 0.95868 | 0.89761 | 0.81818 | 0.90201 | 0.71062 | 0.77147 | 2.80345 | 1.02134 | 0.000653595 | 0.000653595 | 0.000653595
2 | 22.3771 | 0.71381 | 0.81502 | 0.97236 | 0.60211 | 0.67965 | 0.69142 | 0.50791 | 0.97914 | 1.3699 | 1.26471 | 0.00131155 | 0.00131155 | 0.00131155
3 | 32.713 | 0.74754 | 0.71191 | 0.99748 | 0.55702 | 0.11688 | 0.14924 | 0.0787 | 1.86656 | 3.18953 | 1.72143 | 0.0019607 | 0.0019607 | 0.0019607
4 | 43.0039 | 0.744 | 0.65912 | 0.99861 | 0.74324 | 0.70563 | 0.77809 | 0.57996 | 0.88101 | 1.03727 | 1.12986 | 0.0019604 | 0.0019604 | 0.0019604
5 | 53.2939 | 0.70974 | 0.62942 | 0.9763 | 0.95649 | 0.94372 | 0.97539 | 0.79531 | 0.69161 | 0.59648 | 1.01321 | 0.0019472 | 0.0019472 | 0.0019472
6 | 63.6044 | 0.66269 | 0.57963 | 0.95463 | 0.03579 | 0.05195 | 0.00538 | 0.00397 | 2.39943 | 7.08306 | 2.30097 | 0.001934 | 0.001934 | 0.001934
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

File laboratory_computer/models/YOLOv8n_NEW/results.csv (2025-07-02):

epoch | time | train/box_loss | train/cls_loss | train/dfl_loss | metrics/precision(B) | metrics/recall(B) | metrics/mAP50(B) | metrics/mAP50-95(B) | val/box_loss | val/cls_loss | val/dfl_loss | lr/pg0 | lr/pg1 | lr/pg2
1 | 9.49492 | 0.65393 | 2.03702 | 0.93301 | 1 | 0.24334 | 0.58327 | 0.46634 | 0.59904 | 2.75032 | 0.85372 | 0.000653595 | 0.000653595 | 0.000653595
2 | 17.8746 | 0.64633 | 1.20939 | 0.90324 | 0.92837 | 0.91775 | 0.95093 | 0.73915 | 0.74311 | 1.38432 | 0.94065 | 0.00131155 | 0.00131155 | 0.00131155
3 | 26.5419 | 0.66298 | 1.0345 | 0.934 | 0.98654 | 0.95216 | 0.98809 | 0.8009 | 0.68509 | 0.83148 | 0.94924 | 0.0019607 | 0.0019607 | 0.0019607
4 | 34.4283 | 0.66378 | 0.84698 | 0.93951 | 0.97261 | 0.96104 | 0.98835 | 0.83437 | 0.63793 | 0.75168 | 0.9326 | 0.0019604 | 0.0019604 | 0.0019604
5 | 41.8586 | 0.66457 | 0.76319 | 0.93674 | 0.96016 | 0.93893 | 0.97556 | 0.83267 | 0.62511 | 0.69944 | 0.92357 | 0.0019472 | 0.0019472 | 0.0019472
6 | 49.2746 | 0.60704 | 0.62934 | 0.91646 | 0.97395 | 0.97105 | 0.99004 | 0.84922 | 0.56872 | 0.50721 | 0.91768 | 0.001934 | 0.001934 | 0.001934
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

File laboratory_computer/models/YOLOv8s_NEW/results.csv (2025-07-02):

epoch | time | train/box_loss | train/cls_loss | train/dfl_loss | metrics/precision(B) | metrics/recall(B) | metrics/mAP50(B) | metrics/mAP50-95(B) | val/box_loss | val/cls_loss | val/dfl_loss | lr/pg0 | lr/pg1 | lr/pg2
1 | 11.7097 | 0.60282 | 2.10547 | 0.94686 | 0.85008 | 0.95734 | 0.94982 | 0.77708 | 0.58362 | 1.00816 | 0.93531 | 0.000653595 | 0.000653595 | 0.000653595
2 | 22.0979 | 0.62623 | 0.6457 | 0.93801 | 0.85729 | 0.83983 | 0.90749 | 0.69862 | 0.81712 | 0.81113 | 1.05584 | 0.00131155 | 0.00131155 | 0.00131155
3 | 32.3609 | 0.67218 | 0.65117 | 0.97088 | 0.96613 | 0.74097 | 0.87847 | 0.6992 | 0.85807 | 0.94715 | 1.14376 | 0.0019607 | 0.0019607 | 0.0019607
4 | 42.7973 | 0.67664 | 0.62403 | 0.9659 | 0.74537 | 0.7013 | 0.77533 | 0.55825 | 0.94901 | 1.07175 | 1.17193 | 0.0019604 | 0.0019604 | 0.0019604
5 | 53.0556 | 0.65748 | 0.5795 | 0.95485 | 0.90684 | 0.87879 | 0.94673 | 0.77522 | 0.67075 | 1.20992 | 0.99408 | 0.0019472 | 0.0019472 | 0.0019472
6 | 63.2471 | 0.623 | 0.51667 | 0.93429 | 0.95242 | 0.95317 | 0.96979 | 0.82339 | 0.60715 | 0.51175 | 0.97658 | 0.001934 | 0.001934 | 0.001934
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

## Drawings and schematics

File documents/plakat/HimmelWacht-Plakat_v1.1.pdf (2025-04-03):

# HimmelWacht

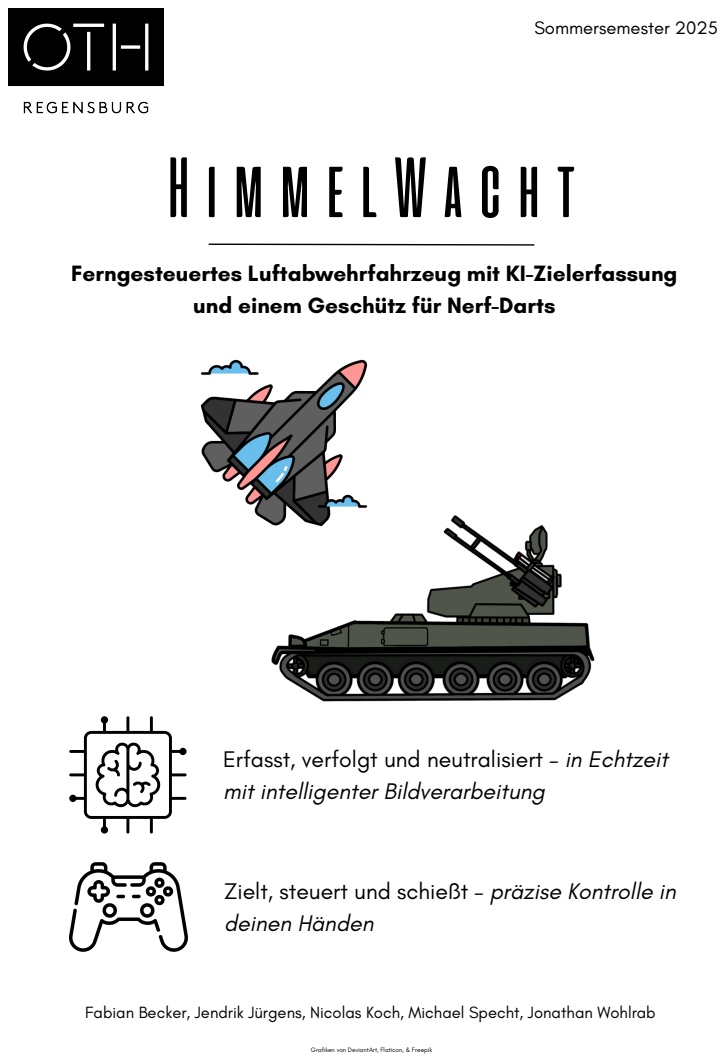
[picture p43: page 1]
Sommersemester 2025

Ferngesteuertes Luftabwehrfahrzeug mit KI-Zielerfassung

und einem Geschütz für Nerf-Darts

Erfasst, verfolgt und neutralisiert – in Echtzeit
mit intelligenter Bildverarbeitung

Zielt, steuert und schießt – präzise Kontrolle in
deinen Händen

Fabian Becker, Jendrik Jürgens, Nicolas Koch, Michael Specht, Jonathan Wohlrab

Grafiken von DeviantArt, Flaticon, & Freepik

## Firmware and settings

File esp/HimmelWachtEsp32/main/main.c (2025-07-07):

#include "sdkconfig.h"

#include "esp_log.h"
#include "esp_wifi.h"

#include "wifi-stack.h"
#include "mqtt-stack.h"
#include "ds4-driver.h"
#include "vehicle-control.h"
#include "motor-driver.h"
#include "diff-drive.h"
#include "platform-control.h"
#include "fire-control.h"

// Define GPIO pins for motors
#define RIGHT_MOTOR_PWM_GPIO 23
#define RIGHT_MOTOR_DIR_GPIO 22

#define LEFT_MOTOR_PWM_GPIO 27
#define LEFT_MOTOR_DIR_GPIO 26

#define MAX_INPUT_VALUE 512

// Enter the Wi-Fi credentials here
#define WIFI_SSID "TI Roboter"
#define WIFI_PASSWORD "ITRobot!"

// Tag for logging
#define TAG "main"

/**
 * @authors Fabian Becker, Michael Specht
 */
void app_main(void){

    // Setup Wifi
    esp_err_t ret = wifi_stack_init(WIFI_SSID, WIFI_PASSWORD);
    if (ret != ESP_OK) {
        ESP_LOGE(TAG, "Failed to connect to Wi-Fi network");
    }

    wifi_ap_record_t ap_info;
    ret = esp_wifi_sta_get_ap_info(&ap_info);
    if (ret == ESP_ERR_WIFI_CONN) {
        ESP_LOGE(TAG, "Wi-Fi station interface not initialized");
    }
    else if (ret == ESP_ERR_WIFI_NOT_CONNECT) {
        ESP_LOGE(TAG, "Wi-Fi station is not connected");
    }

    ESP_LOGI(TAG, "Wi-Fi stack successfully initialized");

    // Configure MQTT component
    mqtt_config_t mqtt_config = {
        .broker_uri = "mqtt://172.16.3.105:1883",  // Broker IP
        .topic = "vehicle/turret/cmd",               // Configurable topic
        .client_id = "esp32_vehicle_01",             // Unique client ID
        .keepalive = 60,                              // Keep alive interval
        .network_timeout_ms = 5000,          // Network timeout in milliseconds
        .reconnect_timeout_ms = 5000,       // Reconnect timeout in milliseconds
        .queue_timeout_ticks = 10,                // Queue timeout in ticks
    };

    // Initialize MQTT component
    ret = mqtt_stack_init(&mqtt_config);
    if (ret != ESP_OK) {
        ESP_LOGE("MAIN", "Failed to start MQTT component: %s", esp_err_to_name(ret));
        return;
    }

    // I²C configuration of PCA9685
    pca9685_config_t pwm_board_cfg = {
        .device_address = 0x40,
        .freq = 50,
        .i2c_port = 0,
        .sda_port = 18,
        .scl_port = 19,
        .internal_pullup = true,
    };

    // Fire control config
    fire_control_config_t fire_control_cfg = {
        .gun_arm_channel = 0,  // Set the channel for the gun arm
        .flywheel_control_gpio_port = 5, // Set the GPIO port for the flywheel control
        .run_on_core = 1                 // Set the core to run on
    };

    // Platform interface configuration
    platform_config_t platform_cfg = {
        .pwm_board_config = pwm_board_cfg,
        .platform_x_channel = 2,
        .platform_x_start_angle = 0,
        .platform_x_left_stop_angle = -90,
        .platform_x_right_stop_angle = 90,
        .platform_y_channel = 1,
        .platform_y_start_angle = 48,
        .platform_y_left_stop_angle = 0,
        .platform_y_right_stop_angle = 80};

    // Left motor configuration
    motor_config_t left_motor_config = {
        .mcpwm_unit = MCPWM_UNIT_0,
        .timer_num = MCPWM_TIMER_0,
        .generator = MCPWM_OPR_A,
        .pwm_signal = MCPWM0A,
        .pwm_gpio_num = LEFT_MOTOR_PWM_GPIO,
        .dir_gpio_num = LEFT_MOTOR_DIR_GPIO,
        .pwm_frequency_hz = 20000,
        .ramp_rate = 5,            // Adjust as needed
        .ramp_intervall_ms = 10,   // Adjust as needed
        .direction_hysteresis = 5, // Adjust as needed
        .pwm_duty_limit = 100,
        .mynr = 0};

    // Right motor configuration
    motor_config_t right_motor_config = {
        .mcpwm_unit = MCPWM_UNIT_0,
        .timer_num = MCPWM_TIMER_1,
        .generator = MCPWM_OPR_A,
        .pwm_signal = MCPWM1A,
        .pwm_gpio_num = RIGHT_MOTOR_PWM_GPIO,
        .dir_gpio_num = RIGHT_MOTOR_DIR_GPIO,
        .pwm_frequency_hz = 20000,
        .ramp_rate = 5,            // Adjust as needed
        .ramp_intervall_ms = 10,   // Adjust as needed
        .direction_hysteresis = 5, // Adjust as needed
        .pwm_duty_limit = 100,
        .mynr = 1};

    // Differential drive configuration
    diff_drive_config_t diff_drive_config = {
        .max_input = MAX_INPUT_VALUE,
        .cmd_queue_size = 10,
        .recovery_time_ms = 1000,
        .task_priority = 0,
        .task_stack_size = 4096,
        .task_core_id = 0,
        .task_delay_ms = 50,
        .queue_timout_ms = 10,
    };

    // Configuration for vehicle control interface
    vehicle_control_config_t manual_control_cfg = {
        .button_hold_threshold_us = 1500000, // 1.5 seconds
        .max_deg_per_sec_x = 300,
        .max_deg_per_sec_y = 150,
        .input_processing_freq_hz = 60,
        .deadzone_x = 30,
        .deadzone_y = 100,
        .deadzone_drive_update = 10,
        .core = 1};

    // Initialize platform
    platform_init(&platform_cfg);

    // Initialize the fire control
    fire_control_init(&fire_control_cfg);

    // Initialize differential drive
    diff_drive_handle_t *diff_drive = diff_drive_init(&diff_drive_config,
                                                      &left_motor_config,
                                                      &right_motor_config);

    // Initialize the DS4 controller
    ds4_init();

    // Initialize vehicle control on core 1
    vehicle_control_init(&manual_control_cfg, diff_drive);
}

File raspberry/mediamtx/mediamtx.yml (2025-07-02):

###############################################
# Global settings

# Settings in this section are applied anywhere.

###############################################
# Global settings -> General

# Verbosity of the program; available values are "error", "warn", "info", "debug".
logLevel: info
# Destinations of log messages; available values are "stdout", "file" and "syslog".
logDestinations: [stdout,file]
# If "file" is in logDestinations, this is the file which will receive the logs.
logFile: mediamtx.log
# If "syslog" is in logDestinations, use prefix for logs.
sysLogPrefix: mediamtx

# Timeout of read operations.
readTimeout: 10s
# Timeout of write operations.
writeTimeout: 10s
# Size of the queue of outgoing packets.
# A higher value allows to increase throughput, a lower value allows to save RAM.
writeQueueSize: 1024
# Maximum size of outgoing UDP packets.
# This can be decreased to avoid fragmentation on networks with a low UDP MTU.
udpMaxPayloadSize: 1472

# Command to run when a client connects to the server.
# This is terminated with SIGINT when a client disconnects from the server.
# The following environment variables are available:
# * MTX_CONN_TYPE: connection type
# * MTX_CONN_ID: connection ID
# * RTSP_PORT: RTSP server port
runOnConnect:
# Restart the command if it exits.
runOnConnectRestart: no
# Command to run when a client disconnects from the server.
# Environment variables are the same of runOnConnect.
runOnDisconnect:

###############################################
# Global settings -> Authentication

# Authentication method. Available values are:
# * internal: users are stored in the configuration file
# * http: an external HTTP URL is contacted to perform authentication
# * jwt: an external identity server provides authentication through JWTs
authMethod: internal

# Internal authentication.
# list of users.
authInternalUsers:
  # Default unprivileged user.
  # Username. 'any' means any user, including anonymous ones.
- user: any
  # Password. Not used in case of 'any' user.
  pass:
  # IPs or networks allowed to use this user. An empty list means any IP.
  ips: []
  # List of permissions.
  permissions:
    # Available actions are: publish, read, playback, api, metrics, pprof.
  - action: publish
    # Paths can be set to further restrict access to a specific path.
    # An empty path means any path.
    # Regular expressions can be used by using a tilde as prefix.
    path:
  - action: read
    path:
  - action: playback
    path:

  # Default administrator.
  # This allows to use API, metrics and PPROF without authentication,
  # if the IP is localhost.
- user: any
  pass:
  ips: ['127.0.0.1', '::1']
  permissions:
  - action: api
  - action: metrics
  - action: pprof

# HTTP-based authentication.
# URL called to perform authentication. Every time a user wants
# to authenticate, the server calls this URL with the POST method
# and a body containing:
# {
#   "user": "user",
#   "password": "password",
#   "ip": "ip",
#   "action": "publish|read|playback|api|metrics|pprof",
#   "path": "path",
#   "protocol": "rtsp|rtmp|hls|webrtc|srt",
#   "id": "id",
#   "query": "query"
# }
# If the response code is 20x, authentication is accepted, otherwise
# it is discarded.
authHTTPAddress:
# Actions to exclude from HTTP-based authentication.
# Format is the same as the one of user permissions.
authHTTPExclude:
- action: api
- action: metrics
- action: pprof

# JWT-based authentication.
# Users have to login through an external identity server and obtain a JWT.
# This JWT must contain the claim "mediamtx_permissions" with permissions,
# for instance:
# {
#  ...
#  "mediamtx_permissions": [
#     {
#       "action": "publish",
#       "path": "somepath"
#     }
#   ]
# }
# Users are expected to pass the JWT in the Authorization header or as a query parameter.
# This is the JWKS URL that will be used to pull (once) the public key that allows
# to validate JWTs.
authJWTJWKS:
# name of the claim that contains permissions.
authJWTClaimKey: mediamtx_permissions
# Actions to exclude from JWT-based authentication.
# Format is the same as the one of user permissions.
authJWTExclude: []

###############################################
# Global settings -> Control API
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

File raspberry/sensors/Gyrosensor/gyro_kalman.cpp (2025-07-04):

/*  used Sources: 
    https://github.com/SREERAJSVT/Angle-MPU6050-Gyroscope
    https://electronics.stackexchange.com/questions/142037/calculating-angles-from-mpu6050
    https://invensense.tdk.com/wp-content/uploads/2015/02/MPU-6000-Datasheet1.pdf


    @Author : Nicolas Koch
*/

#include <iostream>
#include <unistd.h>
#include <fcntl.h>
#include <sys/ioctl.h>
#include <linux/i2c-dev.h>
#include <cmath>
#include <sys/time.h>
#include "kalman.h"

#define MPU6050_ADDR 0x68 // I2C address of the MPU6050
#define MPU6050_REG_PWR_MGMT_1 0x6B
#define OFFSET_SAMPLES 1000
#define CALIBTRATION_SAMPLES 1000
	
float get_dt(struct timeval &prev_time)
{
    struct timeval current_time;
    gettimeofday(&current_time, NULL);
    float dt = (current_time.tv_sec - prev_time.tv_sec) +
               (current_time.tv_usec - prev_time.tv_usec) / 1000000.0f;
    prev_time = current_time;
    return dt;
}

uint8_t get_gyro_scaling(int &file)
{
    uint8_t MPU6050_REG_GYRO_CONFIG = 0x1B;
    write(file, &MPU6050_REG_GYRO_CONFIG, 1); // Set gyro to ±250 degrees/s
    uint8_t scaling;
    read(file, &scaling, 1); // Read the scaling value

    uint8_t fs_sel = (scaling >> 3) & 0x03; // Get the FS_SEL bits
    switch (fs_sel)
    {
    case 0:
        return 131; // ±250 degrees/s
    case 1:
        return 65.5; // ±500 degrees/s
    case 2:
        return 32.8; // ±1000 degrees/s
    case 3:
        return 16.4; // ±2000 degrees/s
    default:
        return 0; // Invalid scaling
    }
}

uint16_t get_accel_scaling(int &file)
{
    uint8_t MPU6050_REG_ACCEL_CONFIG = 0x1C;
    write(file, &MPU6050_REG_ACCEL_CONFIG, 1); // Set accel to ±16384 degrees/s
    uint8_t scaling;
    read(file, &scaling, 1); // Read the scaling value

    uint8_t fs_sel = (scaling >> 3) & 0x03; // Get the FS_SEL bits
    switch (fs_sel)
    {
    case 0:
        return 16384; // ±2 g
    case 1:
        return 8192; // ±4 g
    case 2:
        return 4096; // ±8 g
    case 3:
        return 2048; // ±16 g
    default:
        return 0; // Invalid scaling
    }
}

uint8_t get_raw_data(int16_t &a_x,int16_t &a_y,int16_t &a_z,int16_t &g_x,int16_t &g_y,int16_t &g_z, uint8_t data[14])
{
    // Convert the data to appropriate values
    a_x = (data[0] << 8) | data[1]; // X-axis accelerometer data
    a_y = (data[2] << 8) | data[3]; // Y-axis accelerometer data
    a_z = (data[4] << 8) | data[5]; // Z-axis accelerometer data

    // skip temperature data

    // Convert gyroscope data
    g_x = (data[8] << 8) | data[9];   // X-axis gyroscope data
    g_y = (data[10] << 8) | data[11]; // Y-axis gyroscope data
    g_z = (data[12] << 8) | data[13]; // Z-axis gyroscope data

    return 0;
}

bool perform_self_test(int file)
{
    // Self test registers
    const uint8_t SELF_TEST_X = 0x0D;
    const uint8_t SELF_TEST_Y = 0x0E;
    const uint8_t SELF_TEST_Z = 0x0F;
    const uint8_t SELF_TEST_A = 0x10;

    // Read self-test register

    if (ioctl(file, I2C_SLAVE, MPU6050_ADDR) < 0)
    {
        std::cerr << "Failed to acquire bus access and/or talk to slave" << std::endl;
        close(file);
        return -1;
    }

    char pwr_mgmt_config[2] = {MPU6050_REG_PWR_MGMT_1, 0x00}; // Set gyro to ±250 degrees/s
    if (write(file, pwr_mgmt_config, 2) != 2)
    {
        std::cerr << "Failed to set gyro configuration" << std::endl;
        close(file);
        return -1;
    }
    char gyro_config[2] = {0x1B, 0xE0};
    if (write(file, gyro_config, 2) != 2)
    {
        std::cerr << "Failed to enable gyro self test" << std::endl;
        return false;
    }

    char accel_config[2] = {0x1c, 0xE0};
    if (write(file, accel_config, 2) != 2)
    {
        std::cerr << "Failed to enable accel self test" << std::endl;
        return false;
    }

    uint8_t self_test[4];
    write(file, &SELF_TEST_X, 1);
    if (read(file, self_test, 4) != 4)
    {
        std::cerr << "Failed to read selt test registers" << std::endl;
        return false;
    }

    return true;
}

uint8_t get_offsets(int16_t &MPU6050_AXOFFSET, int16_t &MPU6050_AYOFFSET, int16_t &MPU6050_AZOFFSET,
                    int16_t &MPU6050_GXOFFSET, int16_t &MPU6050_GYOFFSET, int16_t &MPU6050_GZOFFSET,
                    int16_t samples, int& file)
{
    int16_t a_x, a_y, a_z, g_x, g_y, g_z;
    uint8_t data[14];
	uint8_t MPU6050_REG_ACCEL_XOUT_H = 0x3B;
    // Calculate the offsets to zero the sensor
    for (int i = 0; i < samples; i++)
    {
		write(file, &MPU6050_REG_ACCEL_XOUT_H, 1);
		if (read(file, data, 14) != 14)
        {
            std::cerr << "Failed to read data" << std::endl;
            continue;
        }
        
        get_raw_data(a_x, a_y, a_z, g_x, g_y, g_z, data);
        MPU6050_AXOFFSET += a_x;
        MPU6050_AYOFFSET += a_y;
        MPU6050_AZOFFSET += a_z;
        MPU6050_GXOFFSET += g_x;
        MPU6050_GYOFFSET += g_y;
        MPU6050_GZOFFSET += g_z;
        usleep(5000); // Sleep for 4ms
    }
    MPU6050_AXOFFSET /= samples;
    MPU6050_AYOFFSET /= samples;
    MPU6050_AZOFFSET /= samples;
    MPU6050_GXOFFSET /= samples;
    MPU6050_GYOFFSET /= samples;
    MPU6050_GZOFFSET /= samples;
    
    //std::cout << "SET OFFSETS!" << std::endl;

    return 1;
}
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

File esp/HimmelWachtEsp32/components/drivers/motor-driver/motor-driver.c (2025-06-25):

#include "freertos/FreeRTOS.h"
#include "freertos/task.h"
#include "driver/gpio.h"
#include "esp_log.h"
#include "motor-driver.h"
#include <string.h>
#include <math.h>
#include "log_wrapper.h"

#define TAG "MOTOR_DRIVER"

#define MOTOR_TASK_NAME "motor_task"

motor_handle_t *motor_driver_init(const motor_config_t *config);
static esp_err_t init_motor(motor_handle_t *motor, const motor_config_t *config);
esp_err_t motor_driver_emergency_stop(motor_handle_t *motor);
inline bool motor_driver_is_update_necessary(motor_handle_t *motor);
esp_err_t motor_driver_set_speed(motor_handle_t *motor, float duty_cycle, motor_direction_t direction);
static esp_err_t set_pwm(motor_handle_t *motor, float duty_cycle);
static esp_err_t set_dir(motor_handle_t *motor, motor_direction_t direction);
esp_err_t motor_driver_update(motor_handle_t *motor);
void motor_driver_print_all_parameters(motor_handle_t *motor);
esp_err_t motor_driver_deinit(motor_handle_t *motor);

static uint8_t instance_cntr = 0;
uint8_t instance_nr = 0;

motor_handle_t *motor_driver_init(const motor_config_t *config)
{
    // Input validation
    if (config == NULL)
    {
        ESP_LOGE(TAG, "Motor config is NULL");
        return NULL;
    }

    // Create handle
    motor_handle_t *motor = (motor_handle_t *)calloc(1, sizeof(motor_handle_t));
    if (!motor)
    {
        ESP_LOGE(TAG, "Failed to allocate memory for motor handle");
        return NULL;
    }
    else
    {
        motor->current_direction = MOTOR_DIRECTION_STOP;
        motor->current_pwm = 0;
        motor->target_direction = MOTOR_DIRECTION_STOP;
        motor->target_pwm = 0;
        motor->last_update_ms = 0;
        LOGI(TAG, "Motor instance %d created", instance_cntr);
    }

    // Initialize motor
    esp_err_t ret = init_motor(motor, config);
    if (ret != ESP_OK)
    {
        ESP_LOGE(TAG, "Failed to initialize motor");
        free(motor);
        return NULL;
    }

    instance_nr = instance_cntr;
    instance_cntr++;
    motor->initialized = true;
    LOGI(TAG, "Motor driver initialized successfully");

    return motor;
}

static esp_err_t init_motor(motor_handle_t *motor, const motor_config_t *config)
{
    // Store configuration
    memcpy(&motor->config, config, sizeof(motor_config_t));

    esp_err_t ret;
    // Configure + Init direction GPIO
    if (config->dir_gpio_num != GPIO_NUM_NC)
    {
        gpio_config_t io_conf = {
            .pin_bit_mask = (1ULL << config->dir_gpio_num),
            .mode = GPIO_MODE_OUTPUT,
            .pull_up_en = GPIO_PULLUP_DISABLE,
            .pull_down_en = GPIO_PULLDOWN_DISABLE,
            .intr_type = GPIO_INTR_DISABLE,
        };
        ret = gpio_config(&io_conf);
        if (ret != ESP_OK)
        {
            ESP_LOGE(TAG, "Failed to configure direction GPIO %d", config->dir_gpio_num);
            return ret;
        }
    }
    else
    {
        ESP_LOGE(TAG, "Direction GPIO not configured");
        return ESP_ERR_INVALID_ARG;
    }

    // Initialize MCPWM GPIO
    if (config->pwm_gpio_num != GPIO_NUM_NC)
    {
        ret = mcpwm_gpio_init(config->mcpwm_unit, config->pwm_signal, config->pwm_gpio_num);
        if (ret != ESP_OK)
        {
            ESP_LOGE(TAG, "Failed to initialize MCPWM GPIO %d", config->pwm_gpio_num);
            return ret;
        }
    }
    else
    {
        ESP_LOGE(TAG, "MCPWM GPIO not configured");
        return ESP_ERR_INVALID_ARG;
    }

    // Configure MCPWM timer
    mcpwm_config_t pwm_config = {
        .frequency = config->pwm_frequency_hz,
        .cmpr_a = 0,
        .cmpr_b = 0,
        .duty_mode = MCPWM_DUTY_MODE_0,
        .counter_mode = MCPWM_UP_COUNTER,
    };

    ret = mcpwm_init(config->mcpwm_unit, config->timer_num, &pwm_config);
    if (ret != ESP_OK)
    {
        ESP_LOGE(TAG, "Failed to initialize MCPWM timer %d", config->timer_num);
        return ret;
    }

    if (instance_cntr == 0)
    {
        ret = gpio_install_isr_service(0);
        if (ret != ESP_OK)
        {
            ESP_LOGE(TAG, "Failed to install ISR service");
            return ret;
        }
    }

    // Set initial state
    set_dir(motor, motor->target_direction);
    set_pwm(motor, motor->target_pwm);

    return ESP_OK;
}

esp_err_t motor_driver_emergency_stop(motor_handle_t *motor)
{
    if (motor == NULL)
    {
        return ESP_ERR_INVALID_ARG;
    }

    // Set PWM to 0 and direction to stop
    set_pwm(motor, 0);
    set_dir(motor, MOTOR_DIRECTION_STOP);

    return ESP_OK;
}

inline bool motor_driver_is_update_necessary(motor_handle_t *motor)
{
    bool check;
    
    LOGI(TAG, "motor->target_pwm (%.2f) - motor->current_pwm (%.2f): %.2f", motor->target_pwm, motor->current_pwm, fabs(motor->target_pwm - motor->current_pwm));
    LOGI(TAG, "motor->target_direction != motor->current_direction: %d", motor->target_direction != motor->current_direction);

    // check if change in dir or pwm is detected
    if ((fabs(motor->target_pwm - motor->current_pwm) > motor->config.direction_hysteresis) || (motor->target_direction != motor->current_direction))
    {
        check = true;
    }
    else
    {
        check = false;
    }

    LOGI(TAG, "motor_driver_is_update_necessary: %d for instance: %d", check, motor->config.mynr);

    return check;
}

esp_err_t motor_driver_set_speed(motor_handle_t *motor, float duty_cycle, motor_direction_t direction)
{
    if (motor == NULL)
    {
        return ESP_ERR_INVALID_ARG;
    }

    motor->target_pwm = duty_cycle;
    motor->target_direction = direction;

    return ESP_OK;
}

static esp_err_t set_pwm(motor_handle_t *motor, float duty_cycle)
{
    if (duty_cycle < 0)
    {
        duty_cycle = 0;
    }
    if (duty_cycle > motor->config.pwm_duty_limit)
    {
        duty_cycle = motor->config.pwm_duty_limit;
    }

    mcpwm_set_duty(MCPWM_UNIT_0, motor->config.timer_num, motor->config.generator, duty_cycle);
    mcpwm_set_duty_type(MCPWM_UNIT_0, motor->config.timer_num, motor->config.generator, MCPWM_DUTY_MODE_0);

    return ESP_OK;
}

static esp_err_t set_dir(motor_handle_t *motor, motor_direction_t direction)
{
    switch (direction)
    {
    case MOTOR_DIRECTION_FORWARD:
        gpio_set_level(motor->config.dir_gpio_num, 1);
        break;
    case MOTOR_DIRECTION_BACKWARD:
        gpio_set_level(motor->config.dir_gpio_num, 0);
        break;
    case MOTOR_DIRECTION_STOP:
        // For stop, direction doesn't matter as PWM will be zero
        break;
    default:
        ESP_LOGE(TAG, "Invalid direction: %d", direction);
        return ESP_ERR_INVALID_ARG;
    }

    return ESP_OK;
}
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

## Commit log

2025-04-03 initial commit docs
    [HimmelWacht-GANTT_v0.1.xlsx, HimmelWacht-GANTT_v1.1.xlsx, Teileliste.xlsx]
2025-04-03 Update Teileliste
    [Teileliste.xlsx]
2025-04-03 Last changes Teileliste
    [Teileliste.xlsx]
2025-04-03 Überarbeitung Plakat
    [HimmelWacht-GANTT_v0.1.xlsx, HimmelWacht-GANTT_v1.1.xlsx]
2025-04-09 Updated GANTT Diagramme
    [HimmelWacht-GANTT_v1.3.xlsx]
2025-04-10 Add CAD files Part1
    [Teileliste.xlsx, platform.FCStd, platform.stl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]
2025-04-11 add gun arm files
    [flywheel_final.stl, geschuetz_arm_final.stl, import_flywheel.stl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]
2025-04-13 current state 3d files
    [flywheel-final.stl, flywheel_final.stl, gun-arm.stl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]
2025-04-16 add cam screw hol
    [gun-arm.stl]
2025-04-16 added powerplate design
    [platform.FCStd, powerplate.FCStd, powerplate.stl]
2025-04-22 final powerplate design
    [platform.FCStd, platform.stl, powerplate.FCStd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]
2025-04-22 setup esp32 project
2025-04-27 ds4 driver checkpoint, rumble and led working, connection check and input peek todo
    [platform.FCStd, platform.stl, powerplate-top.FCStd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]
2025-04-27 first working version of driver done
2025-05-01 new parts we need
    [Bestellung2.xlsx]
2025-05-06 add resistors, capacitors
    [Bestellung2.xlsx]
2025-05-07 Order ready
    [Bestellung2.xlsx]
2025-05-14 Resolve "redo gun arm design"
    [gun-arm.stl, import_motor_mount.stl, left-mag.stl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]
2025-05-15 y axis working
2025-05-18 add IQMath and hold button logic
2025-05-19 get fabi state into driving experience
    [ina226-plate.stl, ina226.FCStd, platform.FCStd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]
2025-05-21 switch forward and backward to be more intuitive
2025-05-21 change left and right motor
2025-05-23 mos holder + case
    [ESP32-case-breakout-board.stl, esp-case-pi5-case-bottom.stl, pi5-case-bottom.3mf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]
2025-05-23 hourlist template added
    [StundenlisteVorlageDT.xlsx, Stundenliste_Fabian_Becker.xlsx]
2025-05-27 Upload Stundenliste Jonathan Wohlrab
    [Stundenliste_Jonathan_Wohlrab.xlsx]
2025-06-10 Resolve "create pololu mount"
    [pololu-mount.stl, pololu.FCStd]
2025-06-10 Resolve "remove fault handling"
    [diff-drive.c, main.c, motor-driver.c]
2025-06-11 Resolve "transform drive logic to IQMath"
    [diff-drive.c]
2025-06-11 hot fix: ramprate 85 -> 5
    [main.c]
2025-06-18 Update cad files
    [ESP32-case-breakout-board.stl, esp-case-pi5-case-bottom.stl, import_pi5_case_bottom.stl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]
2025-06-18 Fix 3D files
    [esp-case-bottom.stl, esp-case-top.stl, ina226.FCStd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]
2025-06-18 cleanup: remove atmega328p samples
2025-06-18 cleanup: add cad readme
2025-06-18 hotfix: add smoothing filter to platform rotation
2025-06-22 add comments to motor-driver header file
2025-06-24 michi cad init ready
2025-06-24 cad michi with images; sketch esp
2025-06-24 add michi up to ll-driver test
2025-06-25 Update hour list
    [Stundenliste_Fabian_Becker.xlsx]
2025-06-25 bugfix: only add mqtt commands to queue if in semi automatic mode
    [vehicle-control.c]
2025-06-29 add some text
    [Stundenliste_Fabian_Becker.xlsx]
2025-07-01 finished cad chapters
2025-07-02 finished servo section
2025-07-02 checkpoint ds4 driver
2025-07-02 added gyro text and a bit webserver
2025-07-04 Add gyro_kalman.cpp
2025-07-04 finished ds4 driver doku
2025-07-06 raspberry chapters finished
2025-07-06 added kalman filter calculation
2025-07-06 proofreading of cad and raspberry chapter
2025-07-07 cleanup esp32 code
2025-07-10 Update ultrasonic code and add systemd services
2025-07-12 Hinzufügen Projektplanung und Stromversorgung Raspi
2025-07-14 add excel format
    [Stundenliste_Michael_Specht.xlsx]
2025-07-14 Rechtschreibfehler und co raus
